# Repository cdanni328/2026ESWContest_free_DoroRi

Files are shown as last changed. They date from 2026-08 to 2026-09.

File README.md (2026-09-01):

# 2026ESWContest_free_DoroRi
Reporsitory of Team DoroRi for The World Embedded Software Contest 2026

# DORORI 프로젝트 — 모터 통합 서버 2종

이 폴더에는 같은 카메라·YOLO 판단·A4988 모터 제어 상태머신을 공유하는 두 실행 버전이 들어 있습니다.

- `dorori_debug_speed.py` + `dorori_debug_speed.html`
  - OBD-II 없이 HTML에서 차량 속도만 수동 입력
  - 연석·배수로·맨홀·노면 판단은 실제 카메라와 두 가중치로 수행
- `dorori_obd.py` + `dorori_obd.html`
  - USB ELM327 계열 OBD-II 어댑터에서 실제 차량 속도를 읽음
  - 속도 데이터가 끊기거나 오래되면 `FAULT` 처리하고, 발판이 움직이는 중이면 조기 수납 요청

가중치 기본 경로는 서버 파일과 같은 폴더의 다음 파일입니다.

- `best_selection.pt`: segmentation (`curb`, `drainage`, `manhole`)
- `best노면.pt`: road-surface classification

> 현재 업로드된 segmentation 가중치에는 별도의 `obstacle` 클래스가 없습니다. 따라서 이 코드의 시각 판단 대상은 연석·배수로·맨홀과 노면입니다.

---

## 1. 기본 동작

운전자가 화면의 판단 스위치를 켜면 다음 순서로 동작합니다.

1. 속도가 `5.0 km/h`를 초과하면 카메라 판단과 전개를 대기합니다.
2. `0.1 < 속도 <= 5.0 km/h`에서는 카메라 판단 결과만 표시하며 모터를 전개하지 않습니다.
3. 속도가 `0.1 km/h` 이하가 되면 **정차 이후 새로 얻은 카메라 결과**를 기다립니다.
4. 속도가 정차 기준 이하로 0.1초 연속 유지되고 결과가 `YELLOW`이면 모터 사이클을 한 번만 시작합니다.
5. 음성과 물리 동작을 다음 순서로 분리합니다.
   - `연석 감지, 발판 전개합니다` 안내 완료
   - 발판 전개
   - `전개 완료` 안내 완료
   - 발판 유지
   - `발판 회수합니다` 안내 완료
   - 발판 회수
   - `회수 완료` 안내
   - `ko-KR-SunHiNeural` 여성 음성으로 생성한 고정 MP3를 사용하며 OS·브라우저 TTS 음성에 의존하지 않습니다.
   - 브라우저가 각 MP3의 실제 재생 종료를 서버에 확인해 준 뒤에만 다음 동작을 시작합니다.
   - 정차 시점부터 회수 완료 안내까지 10초를 넘지 않도록 유지 시간을 자동 단축합니다.
6. 속도가 다시 올라가거나, 비전/속도 오류가 생기거나, 시스템을 끄거나, `조기 회수`를 누르면:
   - 유지 중이면 남은 유지 시간을 기다리지 않고 수납
   - 전개 도중이면 회수 안내 후 **실제로 전개된 펄스 수만큼만 역회전**
7. 같은 판단 세션에서는 `deploy_latched`로 반복 전개를 막습니다.

음성 재생 시간과 모터 속도에 따라 실제 유지 시간은 달라집니다. 유지 시간은 `MOTOR_HOLD_SEC`가 상한이며, 10초 제한에 필요한 회수 안내·회수 시간을 먼저 확보합니다.

### 판단 우선순위

1. 연석 감지 → 다른 감지 결과와 관계없이 `YELLOW`, 정차 시 전개
2. 연석 없음 + 배수로 감지 → 노면 불량으로 `RED`, 전개 금지
3. 연석 없음 + 눈·빙판 또는 알 수 없는 노면 → `RED`, 전개 금지
4. 연석·배수로 없음 + dry/wet/water 계열 노면 → `GREEN`

연석과 배수로가 동시에 검출되면 연석을 우선하여 `YELLOW`입니다. 맨홀은 UI에 감지 결과만 표시하며 최종 판단에는 사용하지 않습니다.

현재 `VISION_ROI=(0.0, 0.0, 1.0, 1.0)`으로 카메라 전체 화면을 세그멘테이션과 노면 분류에 사용합니다. 실차 테스트 후 두 서버 파일의 이 값을 정규화 좌표 `(x1, y1, x2, y2)`로 조정하면 두 모델에 같은 ROI가 적용됩니다.

---

## 2. 파일 배치

실행할 때 다음 파일들을 같은 폴더에 둡니다.

```text
2026ESWContest_free_DoroRi/
├── dorori_debug_speed.py
├── dorori_debug_speed.html
├── dorori_obd.py
├── dorori_obd.html
├── audio/
│   ├── announce_deploy.mp3
│   ├── announce_deployed.mp3
│   ├── announce_retract.mp3
│   └── announce_retracted.mp3
├── best_selection.pt
├── best노면.pt
├── requirements.txt
└── README_KO.md
```

모델이나 HTML을 다른 위치에 둘 수도 있지만, 그 경우 아래 환경변수로 경로를 지정해야 합니다.

```bash
SEG_MODEL_PATH=/절대경로/best_selection.pt
CLASSIFY_MODEL_PATH=/절대경로/best노면.pt
```

---

## 3. Raspberry Pi 설치

Raspberry Pi OS 계열에서 권장하는 설치 예시입니다.

```bash
sudo apt update
sudo apt install -y python3-venv python3-gpiozero python3-lgpio

cd ~/2026ESWContest_free_DoroRi
python3 -m venv --system-site-packages .venv
source .venv/bin/activate
python -m pip install --upgrade pip
python -m pip install -r requirements.txt
```

`requirements.txt`의 Ultralytics/OpenCV가 현재 Python에 맞는 NumPy를 함께 설치합니다. `numpy==1.24.4` 고정은 Python 3.12 이상과 호환되지 않으므로 사용하지 않습니다. GPIO 패키지는 Raspberry Pi OS 패키지를 사용하도록 위에서 `apt`로 설치합니다.

### OBD 속도만 터미널에서 시험

전체 서버용 패키지는 필요하지 않습니다. USB ELM327을 연결한 뒤 다음만 설치하고 실행합니다.

```bash
sudo apt update
sudo apt install -y python3-venv

cd ~/2026ESWContest_free_DoroRi
python3 -m venv .venv-obd
source .venv-obd/bin/activate
python -m pip install obd==0.7.3
python SW/test_obd_speed.py --port /dev/ttyUSB0
```

포트 이름을 모르면 먼저 확인합니다.

```bash
ls -l /dev/ttyUSB* /dev/ttyACM* 2>/dev/null
ls -l /dev/serial/by-id/ 2>/dev/null
```

권한 오류가 나면 사용자를 `dialout` 그룹에 추가한 뒤 재부팅합니다.

```bash
sudo usermod -aG dialout "$USER"
sudo reboot
```

복제 ELM327의 응답이 불안정하면 fast 모드를 끄고 제한 시간을 늘립니다.

```bash
python SW/test_obd_speed.py --port /dev/ttyUSB0 --slow --timeout 5
```

---

## 4. A4988 배선

코드는 사용자가 제시한 BCM 핀 맵을 그대로 사용합니다.

| Raspberry Pi BCM | 물리 핀 | A4988 |
|---:|---:|---|
| GPIO17 | 11 | STEP |
| GPIO27 | 13 | DIR |
| GPIO22 | 15 | ENABLE |
| GND | 예: 6 | Logic GND와 공통 접지 |

중요 배선 조건:

- `ENABLE`은 Active-Low입니다. 코드의 `enable_pin.on()`이 실제 GPIO LOW, 즉 드라이버 활성화입니다.
- A4988 `VMOT`에는 모터 전원을 공급하고, Raspberry Pi 5V 핀으로 모터를 구동하지 않습니다.
- Raspberry Pi GND, A4988 logic GND, 모터 전원 GND는 기준 전위를 공유해야 합니다.
- `RESET`과 `SLEEP`은 함께 묶어 VDD에 올려 두는 구성이 일반적입니다.
- VMOT-GND 전해 커패시터는 드라이버 가까이에 배치합니다.
- 6선 스테퍼 모터를 A4988에 연결할 때는 각 코일의 양 끝 4선만 사용하고 센터 탭 2선은 연결하지 않습니다.
- A4988 전류 제한을 모터 정격에 맞게 먼저 설정하십시오.

### 250펄스 완전 전개 확인

실물 발판 시험에서 정방향 `250`펄스로 완전히 전개되는 것을 기준으로 `MOTOR_STEPS_PER_REV=250`을 사용합니다. 수납은 실제 전개된 펄스 수만큼 역방향으로 구동하므로 정상 전개 후에는 역방향 `250`펄스가 출력됩니다. 기구나 A4988 마이크로스텝 설정을 변경하면 필요한 펄스 수도 다시 확인하십시오.

회전 방향이 반대이면 배선을 바꾸지 않고 다음처럼 실행할 수 있습니다.

```bash
MOTOR_DEPLOY_DIRECTION=0 python dorori_debug_speed.py
```

---

## 5. 디버그 버전 실행

### 5-1. GPIO 없이 전체 UI/상태머신 먼저 시험

```bash
cd ~/2026ESWContest_free_DoroRi
source .venv/bin/activate
MOTOR_DRY_RUN=1 python dorori_debug_speed.py
```

`MOTOR_DRY_RUN=1`에서는 실제 GPIO를 건드리지 않지만, 설정한 펄스 시간과 동적으로 계산된 유지 시간을 실제로 진행하며 화면 상태를 확인할 수 있습니다.

### 5-2. 실제 모터 연결 후 실행

```bash
python dorori_debug_speed.py
```

브라우저에서 다음 주소를 엽니다.

```text
http://라즈베리파이_IP:5000
```

라즈베리파이 IP 확인:

```bash
hostname -I
```

HTML 우측 상단 톱니 버튼에서 속도를 `10`, `3`, `0 km/h` 등으로 바꿀 수 있습니다. 속도만 수동이며 카메라와 두 모델은 실제로 동작합니다.

---

## 6. OBD-II 실사용 버전 실행

### 6-1. 포트 확인

USB 어댑터를 연결한 후 다음을 확인합니다.

```bash
ls -l /dev/ttyUSB* /dev/ttyACM* 2>/dev/null
ls -l /dev/serial/by-id/ 2>/dev/null
```

CH340 계열은 보통 `/dev/ttyUSB0`로 나타나지만, `/dev/serial/by-id/...` 경로를 사용하면 재부팅 후에도 더 안정적으로 같은 장치를 지정할 수 있습니다.

현재 사용자를 serial 장치 접근 그룹에 추가합니다.

```bash
sudo usermod -aG dialout "$USER"
```

그 뒤 로그아웃/로그인 또는 재부팅하여 그룹 변경을 적용합니다.

### 6-2. 자동 포트 검색

```bash
cd ~/2026ESWContest_free_DoroRi
source .venv/bin/activate
python dorori_obd.py
```

### 6-3. 포트 직접 지정

```bash
OBD_PORT=/dev/ttyUSB0 python dorori_obd.py
```

안정적인 by-id 경로 예시:

```bash
OBD_PORT=/dev/serial/by-id/usb-장치이름 python dorori_obd.py
```

복제 ELM327에서 빠른 명령 최적화가 문제를 만들 경우:

```bash
OBD_FAST=0 OBD_TIMEOUT_SEC=1.0 OBD_PORT=/dev/ttyUSB0 python dorori_obd.py
```

서버는 표준 Vehicle Speed 명령을 주기적으로 질의합니다. 연속 응답 실패, 연결 해제, 또는 설정 시간 이상 속도 데이터가 갱신되지 않으면 `FAULT`로 전환합니다.

---

## 7. 주요 환경변수

| 변수 | 기본값 | 의미 |
|---|---:|---|
| `STEP_PIN` | `17` | BCM STEP GPIO |
| `DIR_PIN` | `27` | BCM DIR GPIO |
| `ENABLE_PIN` | `22` | BCM ENABLE GPIO, Active-Low |
| `MOTOR_STEPS_PER_REV` | 디버그 `250`, OBD `220` | 전개/회수 한 방향 펄스 수 |
| `MOTOR_FREQUENCY_HZ` | 디버그 `300`, OBD `100` | STEP 펄스 주파수 |
| `MOTOR_HOLD_SEC` | 디버그 `5.0`, OBD `3.0` | 전개 후 유지 시간 상한 |
| `MOTOR_DEPLOY_DIRECTION` | `1` | `1`/`0`으로 전개 방향 반전 |
| `MOTOR_HOLD_TORQUE` | `1` | 유지 중 ENABLE 유지 여부 |
| `MOTOR_DRY_RUN` | `0` | `1`이면 GPIO 없이 시뮬레이션 |
| `CREEP_MAX_KMH` | `5.0` | 판단을 수행하는 최대 저속 |
| `STOP_SPEED_EPSILON_KMH` | `0.1` | 정차로 간주하는 속도 상한 |
| `STOP_DEPLOY_DELAY_SEC` | `0.1` | 연속 정차 후 전개 지연 |
| `CYCLE_MAX_SEC` | `10.0` | 정차부터 회수 완료 안내까지의 제한 |
| `VISION_INTERVAL_SEC` | `1.0` | 비전 추론 주기 |
| `VISION_STALE_SEC` | `5.0` | 비전 결과 유효 시간 |
| `CAMERA_SOURCE` | `0` | OpenCV 카메라 번호 또는 스트림 경로 |
| `SEG_IMGSZ` | `640` | segmentation 입력 크기 |
| `CLASSIFY_IMGSZ` | `224` | 노면 분류 입력 크기 |
| `SEG_CONF` | `0.25` | segmentation confidence threshold |
| `OBD_PORT` | 자동 | OBD serial 포트 |
| `OBD_FAST` | `1` | python-OBD fast 모드 |
| `OBD_TIMEOUT_SEC` | `0.2` | OBD 질의 timeout |
| `OBD_POLL_SEC` | `0.2` | 속도 질의 주기 |
| `OBD_STALE_SEC` | `1.5` | 속도 데이터 유효 시간 |
| `PORT` | `5000` | 웹 서버 포트 |

예시:

```bash
MOTOR_STEPS_PER_REV=250 \
MOTOR_FREQUENCY_HZ=300 \
MOTOR_HOLD_SEC=5 \
CAMERA_SOURCE=0 \
python dorori_obd.py
```

### 유지 토크 설정

기본값 `MOTOR_HOLD_TORQUE=1`은 발판 유지 단계에서 A4988을 계속 활성화하여 정지 토크를 유지합니다. 그만큼 모터와 드라이버가 더 뜨거워질 수 있습니다. 기구가 자체 잠금 또는 기계식 지지 구조로 위치를 유지한다면 다음처럼 유지 중 출력을 끌 수 있습니다.

```bash
MOTOR_HOLD_TORQUE=0 python dorori_obd.py
```

하중을 받는 발판에서 모터 정지 토크만으로 사람의 체중을 지지하는 구조는 사용하지 마십시오.

---

## 8. API 요약

공통:

- `POST /api/start`: 판단 활성화
- `POST /api/stop`: 판단 종료 및 조기 회수 요청
- `GET /api/vision`: UI용 통합 판단/속도/모터 상태
- `GET /api/status`: 모터 상태
- `GET /api/system`: 전체 내부 상태
- `POST /api/deploy`: 정차·최신 YELLOW·미실행 조건을 모두 통과할 때만 수동 사이클 시작
- `POST /api/retract`: 전개/유지 중 조기 수납
- `POST /api/announcement`: UI가 모터 단계별 음성 종료 여부 전달
- `GET /api/health`: 카메라·모델·모터 준비 상태

디버그 버전만:

```bash
curl -X POST http://127.0.0.1:5000/api/debug \
  -H 'Content-Type: application/json' \
  -d '{"speed_kmh": 0}'
```

```bash
curl http://127.0.0.1:5000/api/debug
```

---

## 9. 실제 발판 장착 전 필수 안전 조건

현재 핀 맵에는 리미트 스위치나 절대 위치 센서가 없으므로 이 코드는 **open-loop 펄스 수**로만 위치를 추정합니다. 전원이 꺼진 상태에서 발판이 움직였거나 스텝 손실이 발생하면 소프트웨어의 위치 가정과 실제 위치가 달라집니다.

사람이 올라가는 실제 발판으로 시험하기 전 최소한 다음을 추가해야 합니다.

- 전개 끝/수납 끝 리미트 스위치 또는 위치 센서
- 물리적 스토퍼와 체중을 받는 기계식 잠금/지지 구조
- 모터 과전류·끼임 감지 또는 별도 보호 회로
- 운전자가 즉시 차단할 수 있는 비상 정지
- 문 열림, 기어 위치, 주차 브레이크 등 차량 측 하드웨어 인터록
- 전원 인가 시 수납 원점 확인 또는 homing 절차

리미트 스위치가 없는 현재 버전은 반드시 **발판이 완전히 수납된 알려진 시작 위치**에서 켜고, 처음에는 무부하·저속·짧은 이동량으로 검증하십시오.

또한 Flask 서버는 `0.0.0.0:5000`으로 열리며 별도 인증이 없습니다. 차량 내부의 신뢰할 수 있는 로컬 네트워크에서만 사용하십시오. GPIO를 한 프로세스만 소유하도록 서버를 여러 worker로 복제해 실행하지 마십시오.

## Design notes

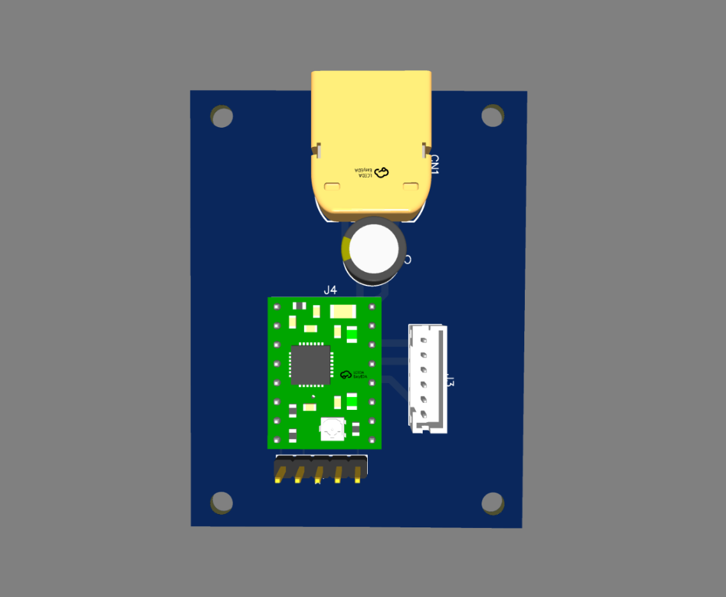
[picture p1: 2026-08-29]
HW/PCB/PCB_3D.png

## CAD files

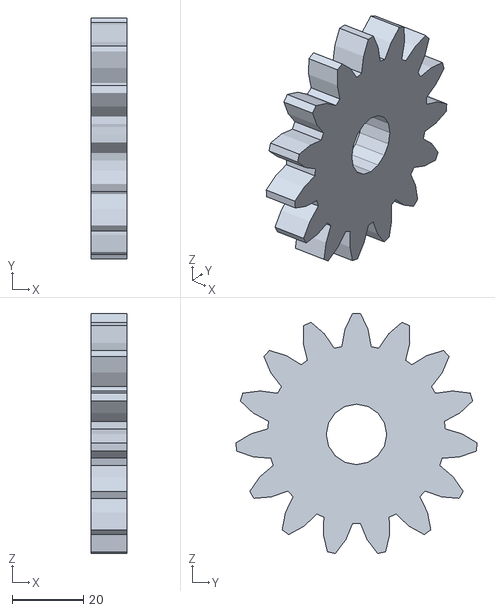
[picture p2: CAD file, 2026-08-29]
HW/PART_DESIGN/grear_4_15.stl
10.0 x 67.8 x 67.5

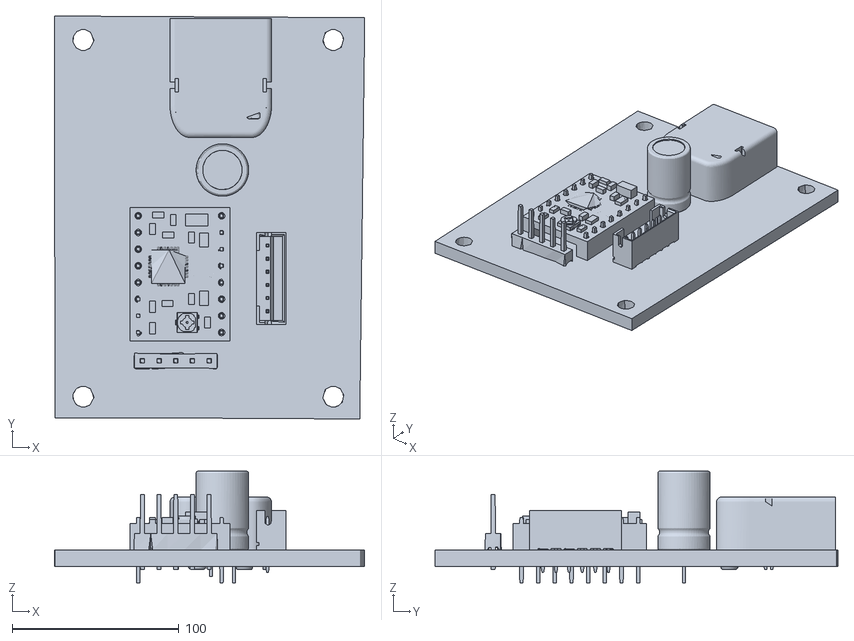
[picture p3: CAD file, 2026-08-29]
HW/PCB/OBJ_PCB_ESW_2.obj
186.3 x 241.8 x 67.0

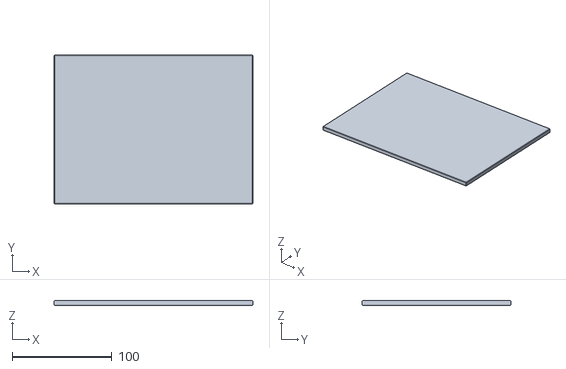
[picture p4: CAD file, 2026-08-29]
HW/PART_DESIGN/PCB_cover_top.stl
200.0 x 150.0 x 5.00

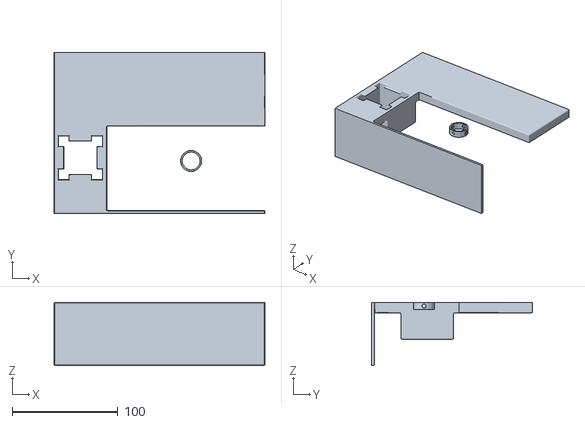
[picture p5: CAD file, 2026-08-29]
HW/PART_DESIGN/motor_case.stl
200.0 x 153.0 x 60.0

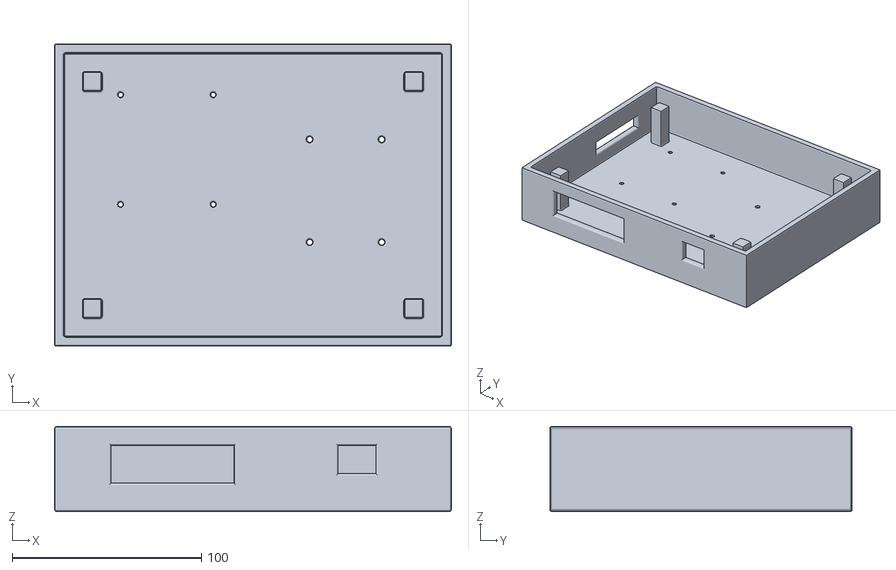
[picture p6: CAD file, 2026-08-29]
HW/PART_DESIGN/pcb_case.stl
210.0 x 160.0 x 45.0

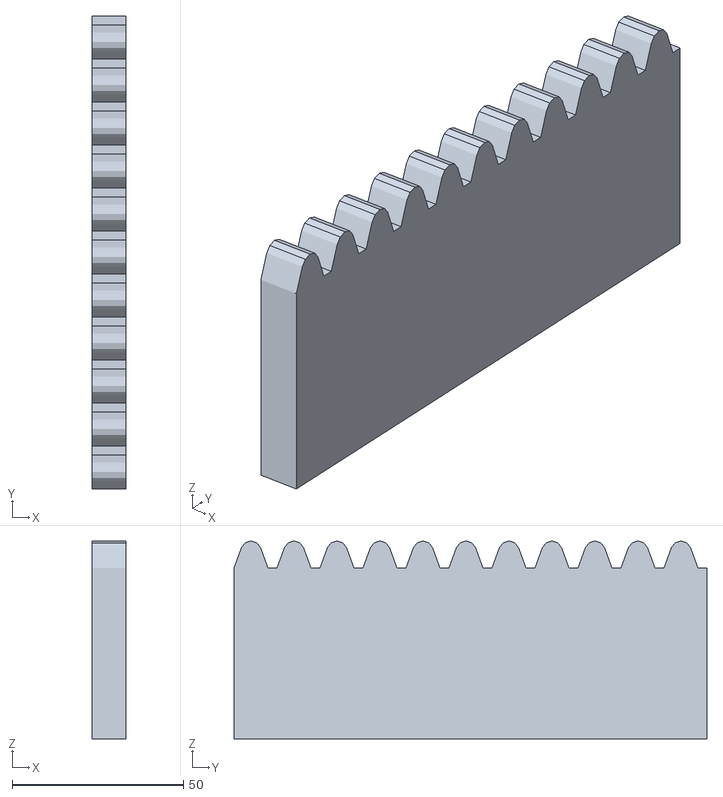
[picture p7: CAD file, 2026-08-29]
HW/PART_DESIGN/lag_gear.stl
10.0 x 138.2 x 57.9

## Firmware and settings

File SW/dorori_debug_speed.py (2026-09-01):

#!/usr/bin/env python3
# -*- coding: utf-8 -*-
"""
dorori_debug_speed.py
DORORI 프로젝트: 실제 카메라/YOLO/모터 + 수동 속도 입력 디버그 서버.

파일 배치(기본값):
- 이 서버 파일
- dorori_debug_speed.html
- best_selection.pt
- best노면.pt

모터 기본값:
- BCM STEP=17, DIR=27, ENABLE=22
- 전개/수납 펄스 수=250
- STEP 주파수=300 Hz
- 단계별 음성 종료 확인 -> 전개 -> 유지 -> 회수 (정차부터 회수까지 최대 10초)

환경변수로 주요 설정을 바꿀 수 있습니다. 자세한 내용은 README_KO.md를 참고하세요.
"""

from __future__ import annotations

import atexit
import math
import os
import threading
import time
from pathlib import Path
from typing import Any

import cv2
from flask import Flask, jsonify, request, send_from_directory

try:
    from gpiozero import OutputDevice
except ImportError:  # MOTOR_DRY_RUN=1이면 GPIO 패키지 없이 UI/상태머신 시험 가능
    OutputDevice = None  # type: ignore[assignment]

try:
    from ultralytics import YOLO
except ImportError:
    YOLO = None  # type: ignore[assignment]




def env_bool(name: str, default: bool) -> bool:
    raw = os.environ.get(name)
    if raw is None:
        return default
    return raw.strip().lower() in {"1", "true", "yes", "on", "y"}


def env_optional_int(name: str) -> int | None:
    raw = os.environ.get(name)
    if raw is None or not raw.strip():
        return None
    return int(raw)


# ───────────────────────────── 기본 설정 ─────────────────────────────
BASE_DIR = Path(__file__).resolve().parent
RUN_MODE = "DEBUG_SPEED"
HTML_FILE_NAME = "dorori_debug_speed.html"
DOOR_ID = "RR"
PORT = int(os.environ.get("PORT", "5000"))

SEG_MODEL_PATH = Path(
    os.environ.get("SEG_MODEL_PATH", str(BASE_DIR / "best_selection.pt"))
).expanduser()
CLASSIFY_MODEL_PATH = Path(
    os.environ.get("CLASSIFY_MODEL_PATH", str(BASE_DIR / "best노면.pt"))
).expanduser()

CAMERA_SOURCE_RAW = os.environ.get("CAMERA_SOURCE", "0")
CAMERA_SOURCE: int | str = (
    int(CAMERA_SOURCE_RAW)
    if CAMERA_SOURCE_RAW.lstrip("-").isdigit()
    else CAMERA_SOURCE_RAW
)
CAMERA_WIDTH = int(os.environ.get("CAMERA_WIDTH", "0"))
CAMERA_HEIGHT = int(os.environ.get("CAMERA_HEIGHT", "0"))
CAMERA_STALE_SEC = float(os.environ.get("CAMERA_STALE_SEC", "1.0"))
CAMERA_RETRY_SEC = float(os.environ.get("CAMERA_RETRY_SEC", "2.0"))

CREEP_MAX_KMH = float(os.environ.get("CREEP_MAX_KMH", "5.0"))
STOP_SPEED_EPSILON_KMH = float(os.environ.get("STOP_SPEED_EPSILON_KMH", "0.1"))
STOP_DEPLOY_DELAY_SEC = float(os.environ.get("STOP_DEPLOY_DELAY_SEC", "0.1"))
CONTROL_PERIOD_SEC = float(os.environ.get("CONTROL_PERIOD_SEC", "0.05"))
VISION_INTERVAL_SEC = float(os.environ.get("VISION_INTERVAL_SEC", "1.0"))
VISION_STALE_SEC = float(os.environ.get("VISION_STALE_SEC", "5.0"))

SEG_IMGSZ = int(os.environ.get("SEG_IMGSZ", "640"))
CLASSIFY_IMGSZ = int(os.environ.get("CLASSIFY_IMGSZ", "224"))
SEG_CONF = float(os.environ.get("SEG_CONF", "0.25"))
INFERENCE_DEVICE = os.environ.get("INFERENCE_DEVICE", "").strip()

# 정규화 좌표 (x1, y1, x2, y2). 현재는 전체 화면이며 실차 테스트 후 보정합니다.
VISION_ROI = (0.0, 0.0, 1.0, 1.0)
REACH_ZONE = (0.25, 0.55, 0.75, 0.95)

# A4988 / 스테퍼 모터
STEP_PIN = int(os.environ.get("STEP_PIN", "17"))
DIR_PIN = int(os.environ.get("DIR_PIN", "27"))
ENABLE_PIN = int(os.environ.get("ENABLE_PIN", "22"))
MOTOR_STEPS_PER_REV = int(os.environ.get("MOTOR_STEPS_PER_REV", "250"))
MOTOR_FREQUENCY_HZ = float(os.environ.get("MOTOR_FREQUENCY_HZ", "300"))
MOTOR_HOLD_SEC = float(os.environ.get("MOTOR_HOLD_SEC", "5.0"))
MOTOR_DEPLOY_DIRECTION = env_bool("MOTOR_DEPLOY_DIRECTION", True)
MOTOR_HOLD_TORQUE = env_bool("MOTOR_HOLD_TORQUE", True)
MOTOR_DRY_RUN = env_bool("MOTOR_DRY_RUN", False)
CYCLE_MAX_SEC = float(os.environ.get("CYCLE_MAX_SEC", "10.0"))
MOTOR_MOVE_BUFFER_SEC = 0.05
ANNOUNCEMENT_RESERVE_SEC = {
    "DEPLOY": 2.25,
    "DEPLOYED": 0.95,
    "RETRACT": 1.24,
    "RETRACTED": 0.86,
}



app = Flask(__name__)
shutdown_event = threading.Event()

vehicle_lock = threading.Lock()
camera_lock = threading.Lock()
perception_lock = threading.Lock()
system_lock = threading.Lock()


# ───────────────────────────── 공유 상태 ─────────────────────────────
vehicle_state: dict[str, Any] = {
    "connected": True,
    "speed_kmh": 10.0,
    "updated_at": time.time(),
    "source": "manual_debug",
    "error": None,
}

camera_state: dict[str, Any] = {
    "connected": False,
    "updated_at": 0.0,
    "error": "카메라 초기화 전",
}
latest_frame: Any = None

perception_state: dict[str, Any] = {
    "model_ready": False,
    "curb": {"detected": False, "reachable": False, "confidence": None},
    "drainage": {"detected": False, "confidence": None},
    "manhole": {"detected": False, "confidence": None},
    "surface": {"class_name": None, "confidence": None, "risky": None},
    "decision": "WAITING",
    "reason_text": "비전 모델 초기화 대기",
    "updated_at": 0.0,
    "error": None,
}

system_state: dict[str, Any] = {
    "door": DOOR_ID,
    "active": False,
    "phase": "IDLE",
    "final_decision": "IDLE",
    "ui_mode": "NEUTRAL",
    "reason_text": "운전자 시작 버튼 대기",
    "stopped_since": None,
    "yellow_since": None,
    "deploy_latched": False,
    "last_motor_action": None,
    "updated_at": time.time(),
}


def decision_to_ui(decision: str) -> str:
    if decision in {"RED", "YELLOW", "GREEN", "FAULT"}:
        return decision
    return "NEUTRAL"


def surface_group(surface_class: str | None) -> str:
    """dry/wet/water는 SAFE, snow/ice는 DANGER, 나머지는 UNKNOWN."""
    if not surface_class:
        return "UNKNOWN"

    value = str(surface_class).strip().lower().replace("_", "-")
    if "snow" in value or "ice" in value:
        return "DANGER"

    if (
        value in {"dry", "wet", "water"}
        or value.startswith("dry-")
        or value.startswith("wet-")
        or value.startswith("water-")
    ):
        return "SAFE"

    return "UNKNOWN"


def decide(
    curb_detected: bool,
    drainage_detected: bool,
    manhole_detected: bool,
    surface_class: str | None,
) -> tuple[str, str]:
    """
    최종 판단 우선순위:
    1) curb -> YELLOW (다른 감지 결과보다 우선)
    2) curb 없음 + drainage -> RED
    3) curb 없음 + snow/ice/알 수 없는 노면 -> RED
    4) curb 없음 + drainage 없음 + 안전 노면 -> GREEN

    manhole은 UI 표시용이며 최종 판단에는 사용하지 않습니다.
    """
    if curb_detected:
        return "YELLOW", "연석이 감지되었습니다. 정차 확인 후 발판을 전개합니다."

    if drainage_detected:
        return "RED", "연석은 없지만 배수로가 감지되어 노면이 불량합니다."

    group = surface_group(surface_class)
    if group == "DANGER":
        return "RED", f"위험 노면이 감지되었습니다 ({surface_class})."

    if group == "UNKNOWN":
        return "RED", f"노면 상태를 안전으로 확인할 수 없습니다 ({surface_class})."

    return "GREEN", f"연석과 배수로가 없고 안전 노면입니다 ({surface_class})."


def crop_frame_to_roi(
    frame: Any, roi: tuple[float, float, float, float]
) -> Any:
    x1, y1, x2, y2 = roi
    if not (0.0 <= x1 < x2 <= 1.0 and 0.0 <= y1 < y2 <= 1.0):
        raise ValueError(f"잘못된 VISION_ROI: {roi}")

    frame_h, frame_w = frame.shape[:2]
    left, top = int(x1 * frame_w), int(y1 * frame_h)
    right = max(left + 1, min(frame_w, int(x2 * frame_w)))
    bottom = max(top + 1, min(frame_h, int(y2 * frame_h)))
    return frame[top:bottom, left:right]


def box_center_in_zone(
    box_xyxy: list[float], frame_w: int, frame_h: int, zone: tuple[float, float, float, float]
) -> bool:
    x1, y1, x2, y2 = box_xyxy
    cx = (x1 + x2) / 2.0 / frame_w
    cy = (y1 + y2) / 2.0 / frame_h
    zx1, zy1, zx2, zy2 = zone
    return zx1 <= cx <= zx2 and zy1 <= cy <= zy2


def names_to_dict(names: Any) -> dict[int, str]:
    if isinstance(names, dict):
        return {int(index): str(name) for index, name in names.items()}
    return {index: str(name) for index, name in enumerate(names)}


def vehicle_snapshot() -> dict[str, Any]:
    with vehicle_lock:
        return dict(vehicle_state)


def camera_snapshot() -> dict[str, Any]:
    with camera_lock:
        return dict(camera_state)


def perception_snapshot() -> dict[str, Any]:
    with perception_lock:
        return {
            "model_ready": perception_state["model_ready"],
            "curb": dict(perception_state["curb"]),
            "drainage": dict(perception_state["drainage"]),
            "manhole": dict(perception_state["manhole"]),
            "surface": dict(perception_state["surface"]),
            "decision": perception_state["decision"],
            "reason_text": perception_state["reason_text"],
            "updated_at": perception_state["updated_at"],
            "error": perception_state["error"],
        }


def system_snapshot() -> dict[str, Any]:
    with system_lock:
        return dict(system_state)


def update_system(**changes: Any) -> None:
    with system_lock:
        system_state.update(changes)
        system_state["updated_at"] = time.time()


def speed_is_fresh(vehicle: dict[str, Any] | None = None) -> bool:
    if vehicle is None:
        vehicle = vehicle_snapshot()
    speed = vehicle.get("speed_kmh")
    return speed is not None and math.isfinite(float(speed)) and float(speed) >= 0.0


def stop_delay_remaining(stopped_since: float | None, now: float | None = None) -> float:
    if stopped_since is None:
        return STOP_DEPLOY_DELAY_SEC
    elapsed = (time.time() if now is None else now) - float(stopped_since)
    return max(0.0, STOP_DEPLOY_DELAY_SEC - elapsed)



def perception_is_fresh(perception: dict[str, Any] | None = None) -> bool:
    if perception is None:
        perception = perception_snapshot()
    if not perception["model_ready"] or perception["error"]:
        return False
    updated_at = float(perception["updated_at"] or 0.0)
    return updated_at > 0.0 and (time.time() - updated_at) <= VISION_STALE_SEC


# ───────────────────────────── 모터 제어 ─────────────────────────────
class MotorController:
    ANNOUNCEMENT_STATES = {
        "ANNOUNCING_DEPLOY",
        "ANNOUNCING_DEPLOYED",
        "ANNOUNCING_RETRACT",
        "ANNOUNCING_RETRACTED",
    }
    BUSY_STATES = ANNOUNCEMENT_STATES | {
        "STARTING",
        "DEPLOYING",
        "DEPLOYED_HOLD",
        "RETRACTING",
    }

    def __init__(self) -> None:
        self._lock = threading.Lock()
        self._thread: threading.Thread | None = None
        self._early_retract = threading.Event()
        self._announcement_event = threading.Event()
        self._announcement_result: str | None = None
        self._cycle_id = 0
        self._step_pin: Any = None
        self._dir_pin: Any = None
        self._enable_pin: Any = None
        self._state: dict[str, Any] = {
            "door": DOOR_ID,
            "ready": False,
            "dry_run": MOTOR_DRY_RUN,
            "state": "INITIALIZING",
            "progress": 0,
            "hold_remaining_sec": None,
            "hold_until": None,
            "source": None,
            "cycle_id": 0,
            "announcement": None,
            "cycle_started_at": None,
            "cycle_deadline_at": None,
            "retracted_at": None,
            "error": None,
            "last_completed_at": None,
            "updated_at": time.time(),
        }
        self._initialize_gpio()

    def _initialize_gpio(self) -> None:
        if MOTOR_STEPS_PER_REV <= 0:
            self._set_error("MOTOR_STEPS_PER_REV는 1 이상이어야 합니다.")
            return
        if MOTOR_FREQUENCY_HZ <= 0:
            self._set_error("MOTOR_FREQUENCY_HZ는 0보다 커야 합니다.")
            return
        if MOTOR_HOLD_SEC < 0:
            self._set_error("MOTOR_HOLD_SEC는 0 이상이어야 합니다.")
            return
        if CYCLE_MAX_SEC <= STOP_DEPLOY_DELAY_SEC:
            self._set_error("CYCLE_MAX_SEC는 STOP_DEPLOY_DELAY_SEC보다 커야 합니다.")
            return
        if MOTOR_DRY_RUN:
            with self._lock:
                self._state.update({
                    "ready": True,
                    "state": "IDLE",
                    "error": None,
                    "updated_at": time.time(),
                })
            print("[MOTOR] MOTOR_DRY_RUN=1: GPIO 없이 실제 시간으로 동작을 시뮬레이션합니다.")
            return

        if OutputDevice is None:
            self._set_error("gpiozero를 불러올 수 없습니다. python3-gpiozero를 설치하세요.")
            return

        try:
            # ENABLE을 가장 먼저 비활성 상태(HIGH)로 설정합니다.
            self._enable_pin = OutputDevice(
                ENABLE_PIN,
                active_high=False,
                initial_value=False,
            )
            self._step_pin = OutputDevice(STEP_PIN, initial_value=False)
            self._dir_pin = OutputDevice(DIR_PIN, initial_value=False)
            self._enable_pin.off()

            with self._lock:
                self._state.update({
                    "ready": True,
                    "state": "IDLE",
                    "error": None,
                    "updated_at": time.time(),
                })

            print(
                f"[MOTOR] GPIO 준비 완료: STEP={STEP_PIN}, DIR={DIR_PIN}, "
                f"ENABLE={ENABLE_PIN}, move_steps={MOTOR_STEPS_PER_REV}, "
                f"frequency={MOTOR_FREQUENCY_HZ:.1f}Hz"
            )
        except Exception as exc:
            self._set_error(f"GPIO 초기화 실패: {exc}")

    def _set_error(self, message: str) -> None:
        with self._lock:
            self._state.update({
                "ready": False,
                "state": "ERROR",
                "announcement": None,
                "error": message,
                "updated_at": time.time(),
            })
        print(f"[MOTOR] 오류: {message}")

    def _update_state(self, **changes: Any) -> None:
        with self._lock:
            self._state.update(changes)
            self._state["updated_at"] = time.time()

    def snapshot(self) -> dict[str, Any]:
        with self._lock:
            data = dict(self._state)

        hold_until = data.get("hold_until")
        if data.get("state") == "DEPLOYED_HOLD" and hold_until:
            data["hold_remaining_sec"] = round(max(0.0, float(hold_until) - time.time()), 2)
        else:
            data["hold_remaining_sec"] = None

        data["busy"] = data.get("state") in self.BUSY_STATES
        deadline_at = data.get("cycle_deadline_at")
        data["cycle_remaining_sec"] = (
            round(max(0.0, float(deadline_at) - time.time()), 2)
            if data["busy"] and deadline_at
            else None
        )
        data.pop("hold_until", None)
        return data

    def request_cycle(
        self, source: str, stopped_since: float | None = None
    ) -> tuple[bool, str]:
        with self._lock:
            if not self._state["ready"]:
                return False, self._state.get("error") or "motor_not_ready"
            if self._state["state"] in self.BUSY_STATES:
                return False, "motor_busy"
            if self._thread is not None and self._thread.is_alive():
                return False, "motor_thread_busy"

            self._cycle_id += 1
            cycle_id = self._cycle_id
            now = time.time()
            cycle_started_at = max(stopped_since or now, now - STOP_DEPLOY_DELAY_SEC)
            cycle_deadline_at = cycle_started_at + CYCLE_MAX_SEC
            if cycle_deadline_at <= now:
                return False, "cycle_deadline_expired"
            self._early_retract.clear()
            self._announcement_event.clear()
            self._announcement_result = None
            self._state.update({
                "state": "STARTING",
                "progress": 0,
                "source": source,
                "cycle_id": cycle_id,
                "announcement": None,
                "cycle_started_at": cycle_started_at,
                "cycle_deadline_at": cycle_deadline_at,
                "retracted_at": None,
                "error": None,
                "updated_at": time.time(),
            })
            self._thread = threading.Thread(
                target=self._cycle_worker,
                args=(cycle_id, source, cycle_deadline_at),
                name=f"motor-cycle-{cycle_id}",
                daemon=True,
            )
            self._thread.start()

        return True, "cycle_started"

    def request_retract_now(self) -> tuple[bool, str]:
        state = self.snapshot()["state"]
        if state in {
            "STARTING",
            "ANNOUNCING_DEPLOY",
            "DEPLOYING",
            "ANNOUNCING_DEPLOYED",
            "DEPLOYED_HOLD",
        }:
            self._early_retract.set()
            return True, "early_retract_requested"
        if state in {"ANNOUNCING_RETRACT", "RETRACTING", "ANNOUNCING_RETRACTED"}:
            return True, "already_retracting"
        return False, "ramp_not_deployed_or_moving"

    def finish_announcement(
        self, cycle_id: int, announcement: str, completed: bool
    ) -> tuple[bool, str]:
        with self._lock:
            if cycle_id != self._state["cycle_id"]:
                return False, "stale_cycle"
            if announcement != self._state.get("announcement"):
                return False, "unexpected_announcement"
            self._announcement_result = "completed" if completed else "failed"
            self._announcement_event.set()
        if not completed:
            self._early_retract.set()
        return True, "announcement_recorded"

    def _await_announcement(
        self,
        state: str,
        announcement: str,
        cycle_id: int,
        deadline_at: float,
        *,
        cancel_on_retract: bool,
    ) -> bool:
        with self._lock:
            self._announcement_result = None
            self._announcement_event.clear()
            self._state.update({
                "state": state,
                "announcement": announcement,
                "cycle_id": cycle_id,
                "updated_at": time.time(),
            })

        while time.time() < deadline_at and not shutdown_event.is_set():
            if cancel_on_retract and self._early_retract.is_set():
                return False
            if self._announcement_event.wait(timeout=0.05):
                with self._lock:
                    return self._announcement_result == "completed"
        return False

    def _set_driver_enabled(self, enabled: bool) -> None:
        if MOTOR_DRY_RUN:
            return
        if self._enable_pin is None:
            raise RuntimeError("ENABLE GPIO가 준비되지 않았습니다.")
        if enabled:
            self._enable_pin.on()   # active_high=False이므로 실제 GPIO LOW
        else:
            self._enable_pin.off()  # 실제 GPIO HIGH

    def _rotate_enabled(
        self,
        direction: bool,
        state_name: str,
        start_progress: float,
        end_progress: float,
        steps: int,
        stop_event: threading.Event | None = None,
    ) -> tuple[int, bool]:
        """
        이미 ENABLE된 상태에서 STEP 펄스를 출력합니다.

        Returns:
            (완료한 펄스 수, 중단 요청으로 조기 종료했는지 여부)
        """
        if steps <= 0:
            return 0, bool(stop_event and stop_event.is_set())

        half_period = 1.0 / (2.0 * MOTOR_FREQUENCY_HZ)

        if not MOTOR_DRY_RUN:
            if self._dir_pin is None or self._step_pin is None:
                raise RuntimeError("STEP/DIR GPIO가 준비되지 않았습니다.")
            if direction:
                self._dir_pin.on()
            else:
                self._dir_pin.off()

        # A4988 DIR setup 여유 시간
        time.sleep(0.001)
        report_every = max(1, steps // 100)

        for step_index in range(steps):
            # 전개 중 속도 증가/시스템 종료/수동 수납 요청이 들어오면
            # 다음 펄스를 내보내기 전에 멈추고, 실제 전개된 만큼만 되감습니다.
            if stop_event is not None and stop_event.is_set():
                if not MOTOR_DRY_RUN and self._step_pin is not None:
                    self._step_pin.off()
                return step_index, True

            if not MOTOR_DRY_RUN:
                self._step_pin.on()
            time.sleep(half_period)
            if not MOTOR_DRY_RUN:
                self._step_pin.off()
            time.sleep(half_period)

            if step_index % report_every == 0 or step_index == steps - 1:
                ratio = (step_index + 1) / steps
                progress = start_progress + (end_progress - start_progress) * ratio
                self._update_state(state=state_name, progress=round(progress, 1))

        return steps, False

    def _cycle_worker(self, cycle_id: int, source: str, deadline_at: float) -> None:
        try:
            if not self._await_announcement(
                "ANNOUNCING_DEPLOY",
                "DEPLOY",
                cycle_id,
                deadline_at,
                cancel_on_retract=True,
            ):
                self._update_state(
                    state="IDLE",
                    progress=0,
                    announcement=None,
                    hold_until=None,
                )
                print(f"[MOTOR] 전개 안내 미완료로 사이클 취소: cycle={cycle_id}")
                return

            move_sec = MOTOR_STEPS_PER_REV / MOTOR_FREQUENCY_HZ + MOTOR_MOVE_BUFFER_SEC
            remaining_speech_sec = sum(
                ANNOUNCEMENT_RESERVE_SEC[name]
                for name in ("DEPLOYED", "RETRACT", "RETRACTED")
            )
            if time.time() + (2 * move_sec) + remaining_speech_sec > deadline_at:
                self._update_state(
                    state="IDLE",
                    progress=0,
                    announcement=None,
                    hold_until=None,
                )
                print(f"[MOTOR] 10초 내 완료 시간 부족으로 사이클 취소: cycle={cycle_id}")
                return

            self._update_state(
                state="DEPLOYING",
                progress=0,
                announcement=None,
                source=source,
                cycle_id=cycle_id,
                hold_until=None,
            )
            self._set_driver_enabled(True)
            time.sleep(0.01)

            deployed_steps, interrupted = self._rotate_enabled(
                direction=MOTOR_DEPLOY_DIRECTION,
                state_name="DEPLOYING",
                start_progress=0,
                end_progress=100,
                steps=MOTOR_STEPS_PER_REV,
                stop_event=self._early_retract,
            )
            deployed_progress = 100.0 * deployed_steps / MOTOR_STEPS_PER_REV
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

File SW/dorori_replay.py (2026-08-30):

#!/usr/bin/env python3
"""렌트카 없이 디버깅용: record_drive 녹화본으로 DORORI 웹·판단·모터 상태머신을 재실행한다."""

from __future__ import annotations

import argparse
import csv
import math
import os
import sys
import time
from dataclasses import dataclass
from pathlib import Path

import cv2


REQUIRED_COLUMNS = {
    "frame_index",
    "elapsed_s",
    "speed_kmh",
    "obd_valid",
    "obd_connected",
    "obd_status",
    "obd_error",
}


class ReplayError(RuntimeError):
    pass


@dataclass(frozen=True)
class ReplayRow:
    frame_index: int
    elapsed_s: float
    speed_kmh: float | None
    obd_valid: bool
    obd_connected: bool
    obd_status: str
    obd_error: str


def build_parser() -> argparse.ArgumentParser:
    parser = argparse.ArgumentParser(
        description="record_drive 영상·OBD 속도 동기 재생 서버"
    )
    parser.add_argument("record_dir", type=Path, help="drive.mp4가 있는 녹화 폴더")
    parser.add_argument(
        "--validate-only",
        action="store_true",
        help="파일과 동기화 데이터만 검사하고 서버는 실행하지 않음",
    )
    parser.add_argument(
        "--allow-real-motor",
        action="store_true",
        help="위험: 확인 문구 입력 후 실제 GPIO 모터 동작 허용",
    )
    return parser


def parse_flag(value: str, name: str, line_number: int) -> bool:
    if value not in {"0", "1"}:
        raise ReplayError(
            f"CSV {line_number}행의 {name}은 0 또는 1이어야 합니다: {value!r}"
        )
    return value == "1"


def load_rows(csv_path: Path) -> list[ReplayRow]:
    try:
        csv_file = csv_path.open(newline="", encoding="utf-8-sig")
    except OSError as exc:
        raise ReplayError(f"CSV를 열 수 없습니다: {csv_path}: {exc}") from exc

    rows: list[ReplayRow] = []
    previous_elapsed: float | None = None
    with csv_file:
        reader = csv.DictReader(csv_file)
        columns = set(reader.fieldnames or ())
        missing = sorted(REQUIRED_COLUMNS - columns)
        if missing:
            raise ReplayError(f"frame_sync.csv 필수 열이 없습니다: {', '.join(missing)}")

        for expected_index, raw in enumerate(reader):
            line_number = expected_index + 2
            try:
                frame_index = int(raw["frame_index"])
                elapsed_s = float(raw["elapsed_s"])
            except (TypeError, ValueError) as exc:
                raise ReplayError(
                    f"CSV {line_number}행의 프레임 번호/시간이 잘못되었습니다."
                ) from exc

            if frame_index != expected_index:
                raise ReplayError(
                    f"CSV {line_number}행 frame_index 불연속: "
                    f"expected={expected_index}, actual={frame_index}"
                )
            if not math.isfinite(elapsed_s):
                raise ReplayError(f"CSV {line_number}행 elapsed_s가 유한수가 아닙니다.")
            if previous_elapsed is not None and elapsed_s <= previous_elapsed:
                raise ReplayError(
                    f"CSV {line_number}행 elapsed_s가 증가하지 않습니다: {elapsed_s}"
                )

            obd_valid = parse_flag(raw["obd_valid"], "obd_valid", line_number)
            obd_connected = parse_flag(
                raw["obd_connected"], "obd_connected", line_number
            )
            speed_kmh: float | None = None
            if obd_valid:
                try:
                    speed_kmh = float(raw["speed_kmh"])
                except (TypeError, ValueError) as exc:
                    raise ReplayError(
                        f"CSV {line_number}행의 유효 속도 값이 없습니다."
                    ) from exc
                if not math.isfinite(speed_kmh) or speed_kmh < 0.0:
                    raise ReplayError(
                        f"CSV {line_number}행의 속도가 비정상입니다: {speed_kmh}"
                    )

            rows.append(
                ReplayRow(
                    frame_index=frame_index,
                    elapsed_s=elapsed_s,
                    speed_kmh=speed_kmh,
                    obd_valid=obd_valid,
                    obd_connected=obd_connected,
                    obd_status=raw["obd_status"],
                    obd_error=raw["obd_error"],
                )
            )
            previous_elapsed = elapsed_s

    if not rows:
        raise ReplayError("frame_sync.csv에 프레임 데이터가 없습니다.")
    return rows


def inspect_video(video_path: Path, *, decode_all: bool) -> int:
    cap = cv2.VideoCapture(str(video_path))
    if not cap.isOpened():
        raise ReplayError(f"영상을 열 수 없습니다: {video_path}")

    try:
        if not decode_all:
            reported = int(round(cap.get(cv2.CAP_PROP_FRAME_COUNT)))
            return max(0, reported)

        count = 0
        while True:
            ok, frame = cap.read()
            if not ok:
                break
            if frame is None:
                raise ReplayError(f"영상 {count}번 프레임이 비어 있습니다.")
            count += 1
        return count
    finally:
        cap.release()


def validate_recording(
    record_dir: Path,
    *,
    decode_all: bool,
) -> tuple[Path, Path, list[ReplayRow], int]:
    record_dir = record_dir.expanduser().resolve()
    if not record_dir.is_dir():
        raise ReplayError(f"녹화 폴더가 없습니다: {record_dir}")

    video_path = record_dir / "drive.mp4"
    csv_path = record_dir / "frame_sync.csv"
    for path in (video_path, csv_path):
        if not path.is_file():
            raise ReplayError(f"필수 파일이 없습니다: {path}")

    rows = load_rows(csv_path)
    video_frames = inspect_video(video_path, decode_all=decode_all)
    if video_frames > 0 and video_frames != len(rows):
        raise ReplayError(
            f"영상/CSV 프레임 수 불일치: video={video_frames}, csv={len(rows)}"
        )
    return video_path, csv_path, rows, video_frames


def print_validation(
    video_path: Path,
    csv_path: Path,
    rows: list[ReplayRow],
    video_frames: int,
) -> None:
    duration_s = rows[-1].elapsed_s - rows[0].elapsed_s
    valid_count = sum(row.obd_valid for row in rows)
    print(f"[VALID] video={video_path}")
    print(f"[VALID] frame_sync={csv_path}")
    print(f"[VALID] video_frames={video_frames or 'unknown'}")
    print(f"[VALID] csv_rows={len(rows)}")
    print(f"[VALID] replay_duration_s={duration_s:.6f}")
    print(f"[VALID] obd_valid={valid_count}, obd_invalid={len(rows) - valid_count}")


def confirm_real_motor() -> bool:
    if not sys.stdin.isatty():
        print(
            "실제 모터 허용은 대화형 터미널에서만 가능합니다.",
            file=sys.stderr,
        )
        return False
    try:
        answer = input(
            "[DANGER] Replay 판단으로 실제 모터가 움직입니다. "
            "계속하려면 REAL MOTOR 입력: "
        )
    except (EOFError, KeyboardInterrupt):
        print("\n실제 모터 허용을 취소했습니다.", file=sys.stderr)
        return False
    if answer != "REAL MOTOR":
        print(
            "확인 문구가 일치하지 않아 실제 모터 허용을 취소했습니다.",
            file=sys.stderr,
        )
        return False
    return True
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

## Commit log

2026-08-29 Add DORORI vision and motor control system
2026-08-29 Add HW/PART_DESIGN STL files
    [PCB_cover_hat.stl, grear_4_15.stl, lag_gear.stl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]
2026-08-29 PCB design
    [PCB.stl]
2026-08-29 Update PCB design model
    [OBJ_PCB_ESW_2.obj, PCB.stl]
2026-08-29 Rename STL files in HW/PART_DESIGN
    [PCB_cover_top.stl, motor_case.stl]
2026-08-30 obd2 테스트 코드
2026-08-30 실시간 카메라 영상 시각화
2026-08-30 디버깅용 리플레이, yolo 확인 파일
2026-08-31 발판 전개 전 3초 delay
2026-08-31 모터 회전각 수정
2026-08-31 모터 스텝 수 250
2026-09-01 음성 변경
